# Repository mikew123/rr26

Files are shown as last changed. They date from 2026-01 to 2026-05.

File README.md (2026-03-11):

# DESCRIPTION
This design is for the ROBORAMA 2026 Indoor robot competition<br>
The 2025 robot hardware and code will be used with modifications.<br>
The 2025 ROS based code will be reused, the NAV2 navigation code needs help to allow the robot to move faster.<br>

## DPRG competitions
This robot will compete in the following 4 contests. Barrell racing is a new attempt this year<br>
- 6 Can<br>
https://www.dprg.org/wp-content/uploads/2019/01/sixcan-20190119.pdf<br>
- 4 Corner<br>
https://www.dprg.org/wp-content/uploads/2018/09/four_corners-201804303.pdf<br>
- Quick Trip<br>
https://www.dprg.org/wp-content/uploads/2018/09/quick_trip_v20180130_3.pdf<br>
- Barrell Race<br>
https://www.dprg.org/wp-content/uploads/2025/03/barrel_racing_v20250320.pdf<br>

## Hardware modifications
- The rear IR sensor array and front TOF sensor will be removed
- The LIDAR will be lowered so that it can detect the cans on the field  as well as the walls (the 2025 LIDAR only detected the walls for localization and not the cans), this replaces the front TOF sensor and rear sensors.
- The Raspberry Pi Screen will be removed
- The power module will be improved with better regulators
- The wheel controller module will be moved to make room for a WIFI router in the back
- The caster mount will be filled with lead instead of pennys for for weight and stability
- The can detect switch (or some other sensor) will be mounted on the new can catch 
- A new  3D printed can catch will help keep the cans upright after grabbing - the 2025 design allowed the cans to slide a bit under the chassis

## 2025 Robot Pictures Before Modifications:
Top of robot:<br>
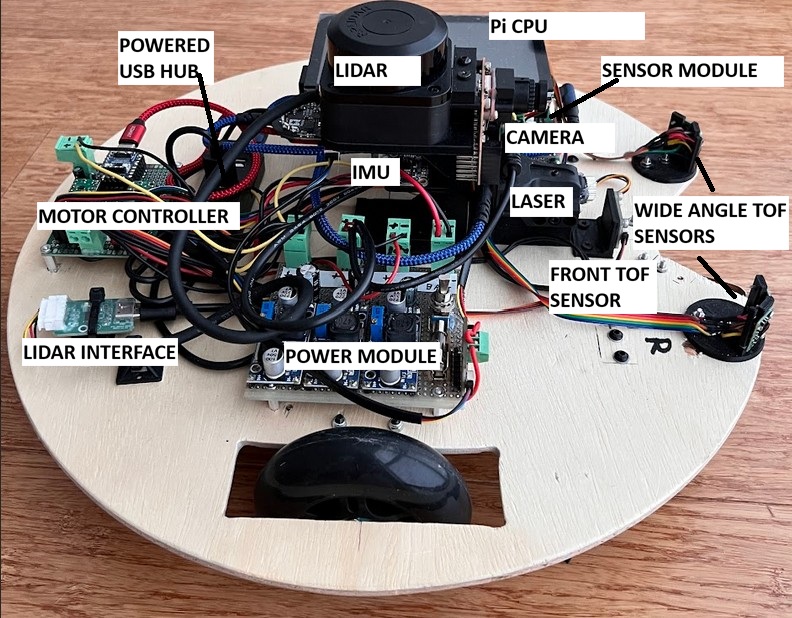
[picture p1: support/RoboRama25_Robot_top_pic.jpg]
Robot top
 <br>
Bottom of robot:<br>
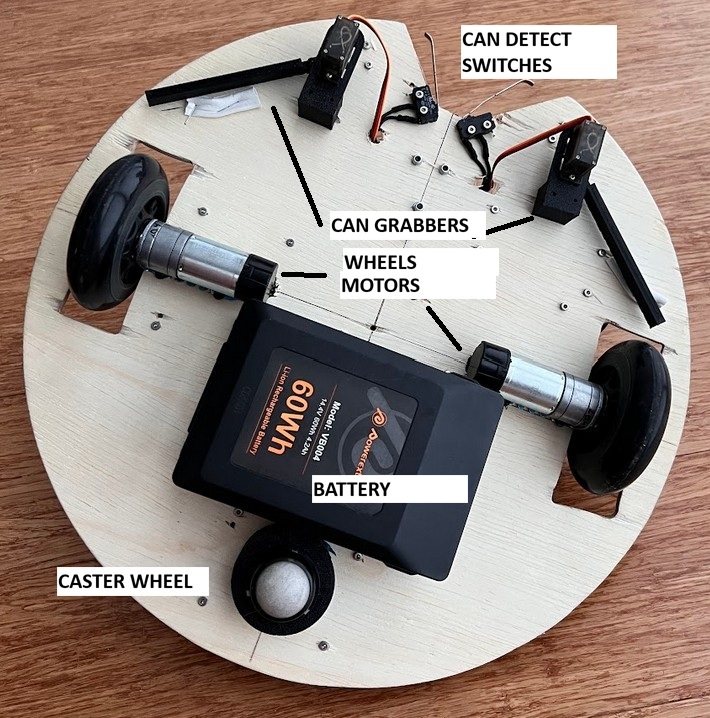
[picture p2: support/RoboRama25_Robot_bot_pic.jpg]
Robot top
 <br>

## Code modifications
- Create a new "scan_obj" topic that blocks the scan rays where the can is detected by the camera. This allows the LIDAR to replace the front TOF sensor when approaching the can.

# Documentation
## Block diagram of electronics:
The Rasberry Pi does not supply power directly to any of the peripherals<br>
The peripheral power is supplied from the power supply module<br>
The powered USB hub supplies power for to the peripherals connected to it<br>
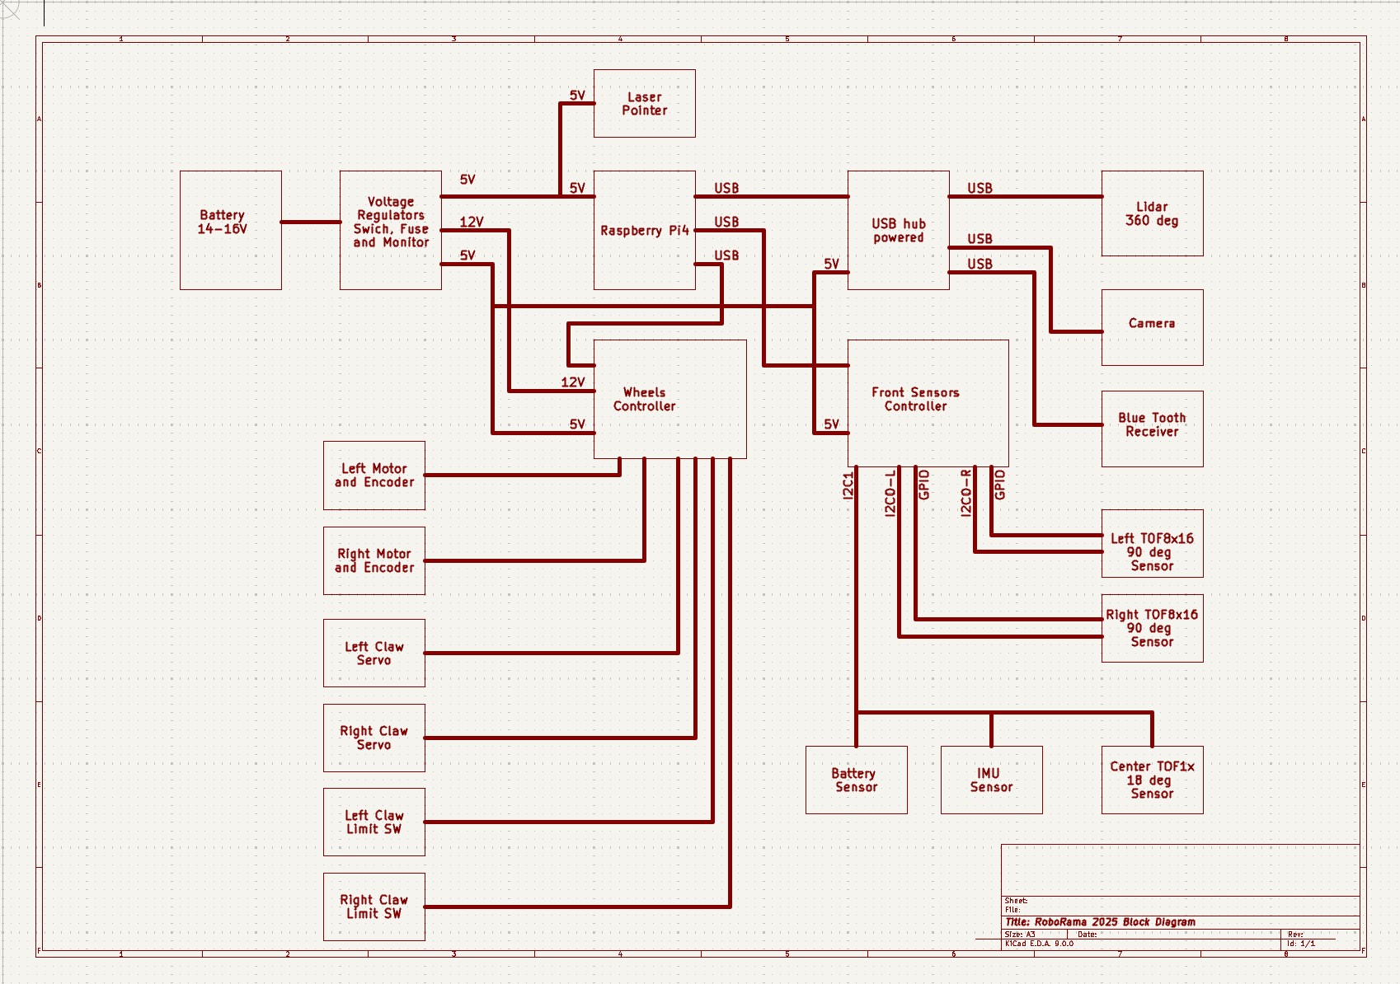
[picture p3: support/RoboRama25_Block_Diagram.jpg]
Block diagram
 <br>

## Schematics:
Power Supply board:<br>
There are 3 voltage regulators. 12V for the wheel motors. A 5V for the Pi and 5V for the peripherals<br>
The Peripheral 5V are bumped up 0.7 volts or so to compensate for the reverse protection diodes<br>
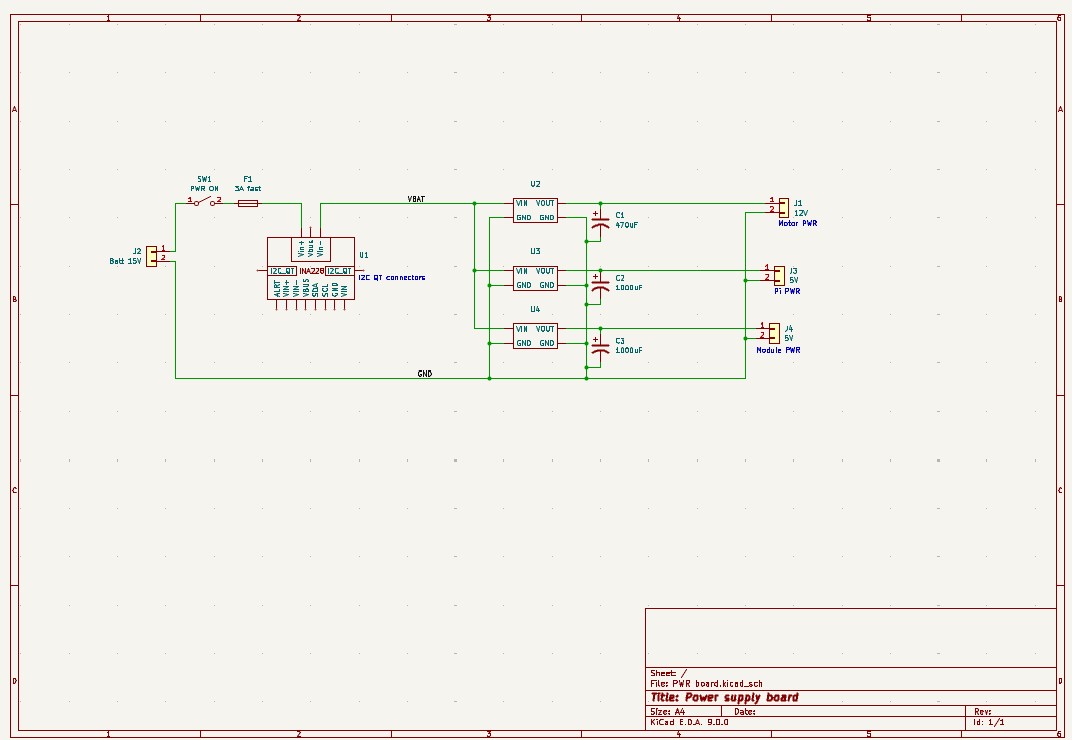
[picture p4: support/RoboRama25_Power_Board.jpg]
Power Supply board
 <br>

Front Sensors Controller board:<br>
The 5V input has a reverse protection diode, the 5V input level is expected to be 5.7V or so to compensate for the diod drop. The 3.3V to the sensors is from a regulator since they need more power than the uC internal regulator can safely generate. The 3.3V regulator can be disabled to reset the VL53L4CX sensors before assigning I2C addresses. The RP2040 module 3.3V output is not used.<br>
The four VL53L4CX sensors are on the I2C0 bus and the I2C1 bus is a QT connector which connects to the other sensors.<br>
The wiring of the VL53L4CX sensors is shown on the schematic, this wiring is not on the Front Sensor Controller board.<br>
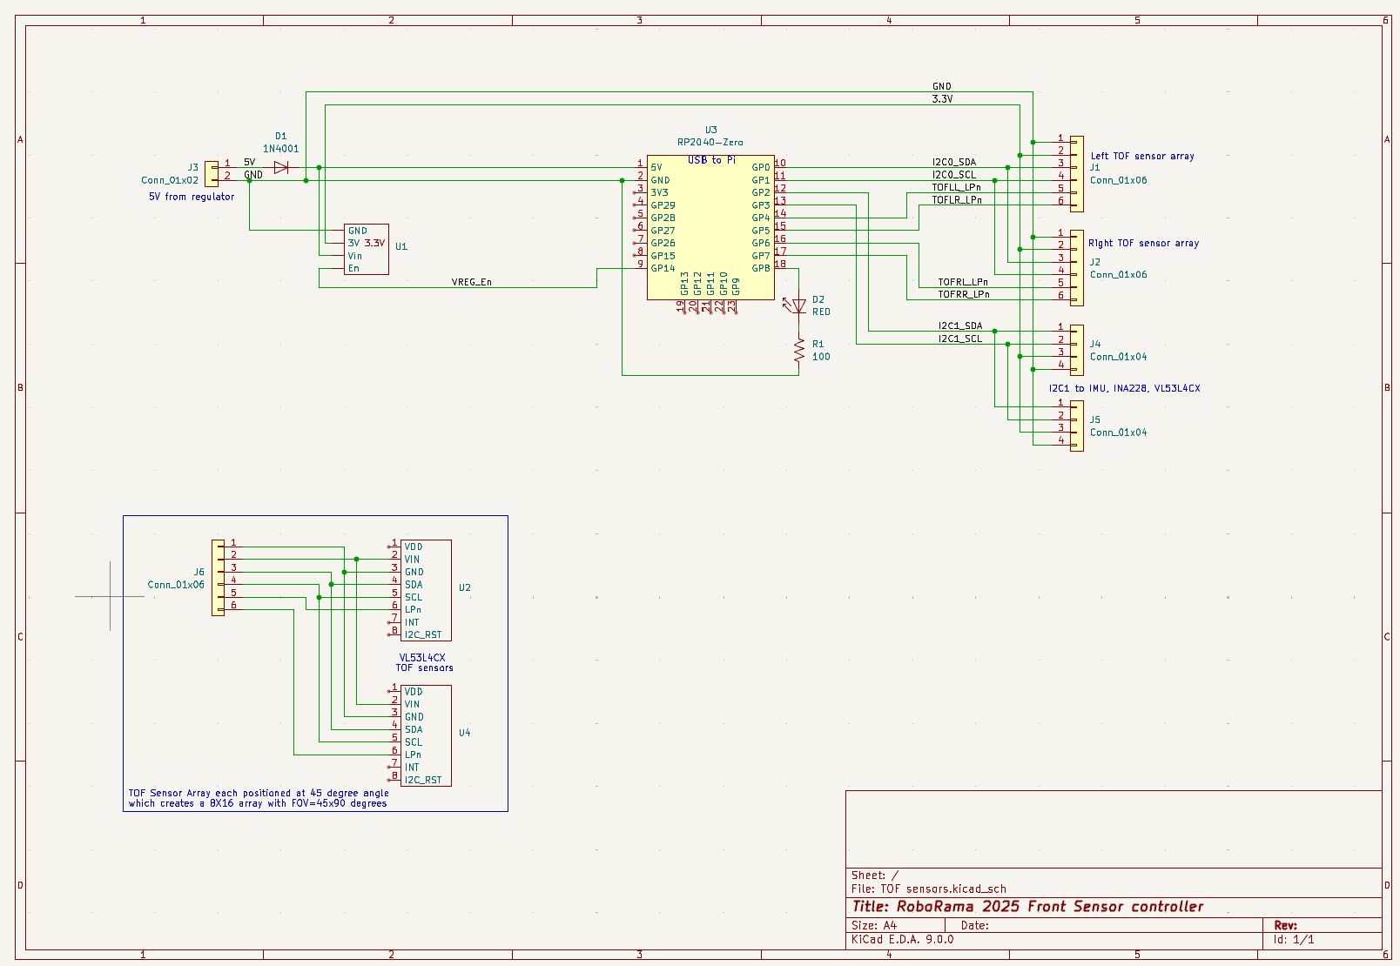
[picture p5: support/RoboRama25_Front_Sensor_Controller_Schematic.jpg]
Front Sensor Controller
 <br>

Wheels Controller board:<br>
The 5V input has a reverse protection diode, the 5V input level is expected to be 5.7V or so to compensate for the diod drop. The RP2040 module 3.3V output powers the pod encoder sensors which do not require a lot of power.<br>
The 12V powers the MP6550 Wheel motor controllers which are connected with a 6 pin cable. The cable also has the motor encoder signals that are powered by 5V and the level shifter connects the signals to the 3.3V GPIO pins of the controller. There is also 4 pin connectors to pod odomtry sensors used on the 2024 robot but not this year.<br>
The 3 pin connectors are for the servos that control the claws operate on 5V and work with the 3.3V GPIO signals. There is a set 2 pin connectors for the limit switches that trip when the can is firmly gripped by the claws, the GPIO pins are configured with internal pull-up resistors so the switches pull the pin levels low when tripped.<br>
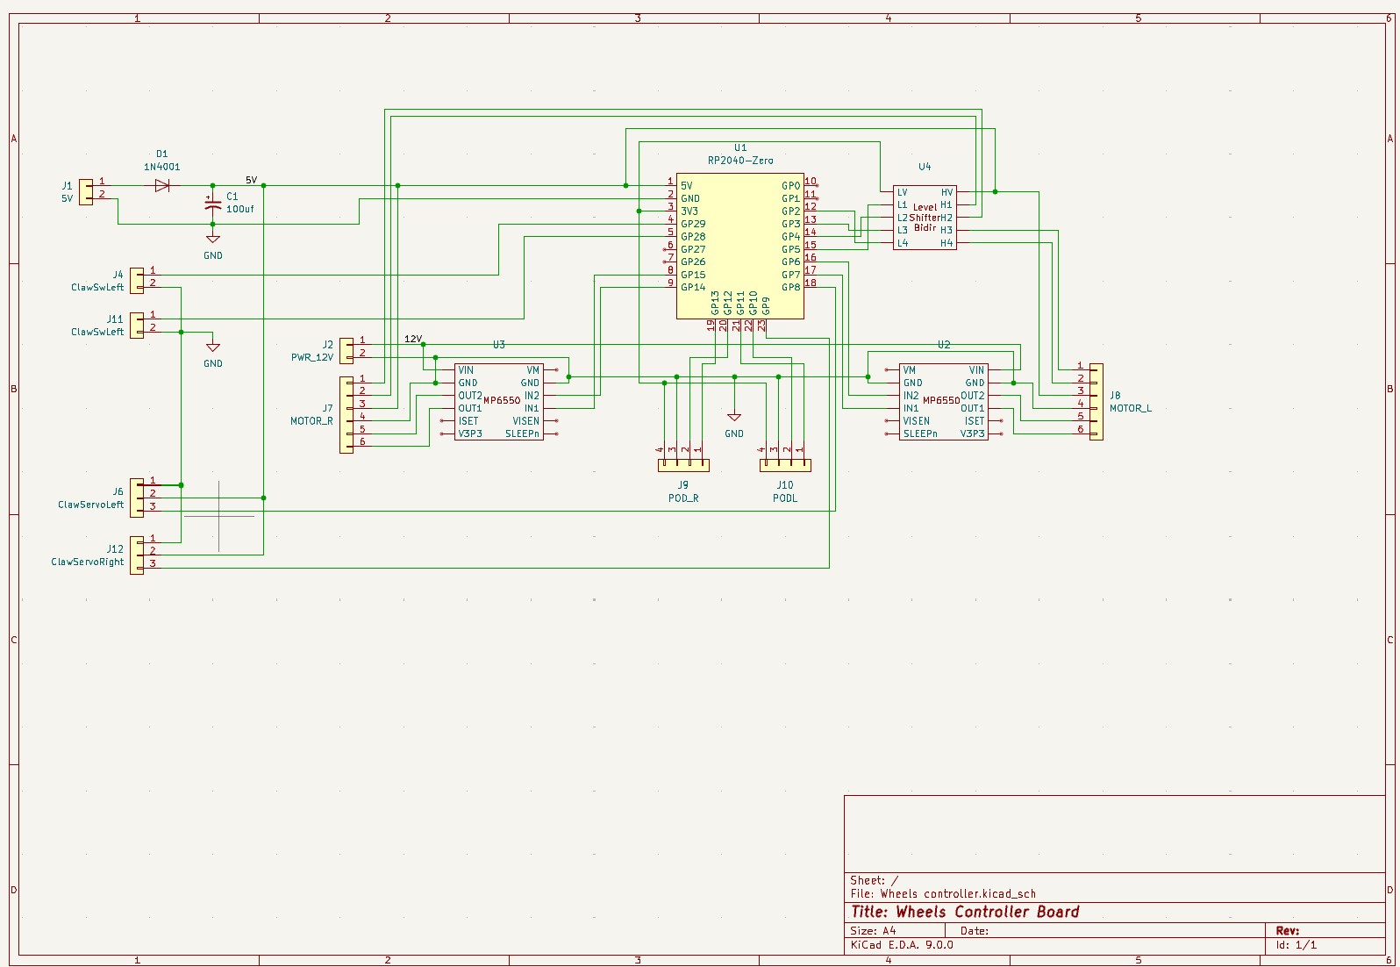
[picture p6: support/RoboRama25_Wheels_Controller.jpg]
Wheels Controller board
 <br>

# ROS2 node package Roborama25 Stuff
(NOTE: These descriptions are created using Co-Pilot)<br>
This package contains nodes and utilities for controlling and managing the Roborama25 robot.<br>

This command line compiles and launches the roborama25 project:<br>
clear; colcon build; source install/setup.bash ; ros2 launch roborama25_stuff roborama25_lc_nav2_bringup_launch.py

## Nodes

### `roborama25_wheel_controller_node_lc`

#### Description
The `roborama25_wheel_controller_node_lc` is a ROS 2 lifecycle node designed to control the robot's differential drive wheels and provide odometry data for the navigation stack. It communicates with a microcontroller (e.g., Raspberry Pi Pico) over a serial interface to send wheel velocity commands and receive encoder data.

#### Features
- **Lifecycle Management**: Implements lifecycle states (`on_configure`, `on_activate`, `on_deactivate`, `on_cleanup`, `on_shutdown`, `on_error`) to manage hardware connections and ROS 2 communications.
- **Wheel Control**: Converts `/cmd_vel` messages into individual wheel velocities and sends them to the microcontroller.
- **Odometry Calculation**: Processes encoder data to calculate the robot's position and orientation, publishing odometry data to the `/wheel_odom` topic.
- **TF Broadcasting**: Broadcasts the transform (`odom -> base_footprint`) using calculated odometry data.
- **Joystick Integration**: Supports joystick-based manual control for resetting encoders and controlling a claw mechanism.
- **Serial Communication**: Handles serial communication with the microcontroller for sending and receiving data.
- **Claw Control**: Processes JSON commands from the `/robot_json` topic to control a claw mechanism.

#### Topics
- **Subscriptions**:
  - `/cmd_vel`: Receives velocity commands for the robot.
  - `/joy`: Processes joystick inputs for additional controls.
  - `/robot_json`: Processes JSON commands for the claw mechanism.
  - `encoders_msg`: Reads encoder data from the serial interface.

- **Publications**:
  - `/wheel_odom`: Publishes odometry data for the navigation stack.
  - `encoders_msg`: Publishes raw encoder data received from the serial interface.
  - `wheel_debug_msg`: Publishes debug messages for wheel-related calculations.

#### Parameters
- **Wheel Configuration**:
  - `wheelDiameter`: Diameter of the wheels.
  - `wheelEncoderCounts`: Encoder counts per wheel rotation.
  - `wheelDistance`: Distance between the two wheels.

- **Velocity Limits**:
  - `wheelVelocityAccLimit`: Maximum acceleration for the wheels.
  - `fwdRevMpsMax`: Maximum forward/reverse speed.

- **Serial Configuration**:
  - `wheel_serial_port_name`: Serial port for communication with the microcontroller.
  - `serialTimerRateHz`: Frequency for checking the serial port.

#### Usage
1. Build the package:
   ```bash
   colcon build --packages-select roborama25_stuff

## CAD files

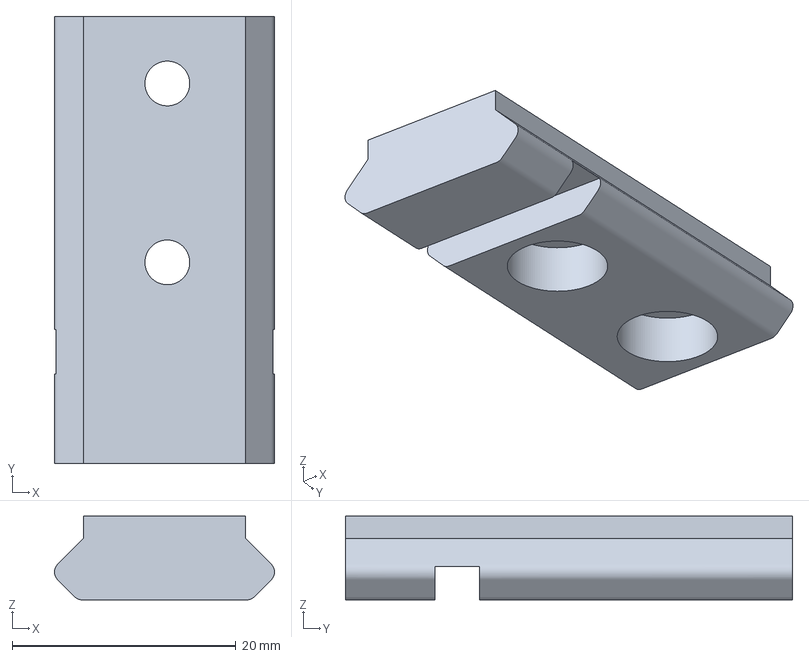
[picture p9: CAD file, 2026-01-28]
3dprinting/Roborama2026-Lasermount.3mf
19.7 x 40.0 x 7.50 mm

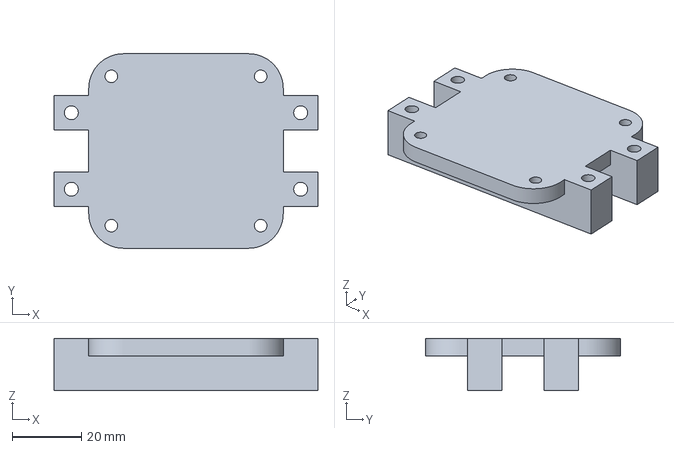
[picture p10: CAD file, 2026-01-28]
3dprinting/Roborama2026-LidarMount.3mf
76.0 x 56.0 x 15.0 mm

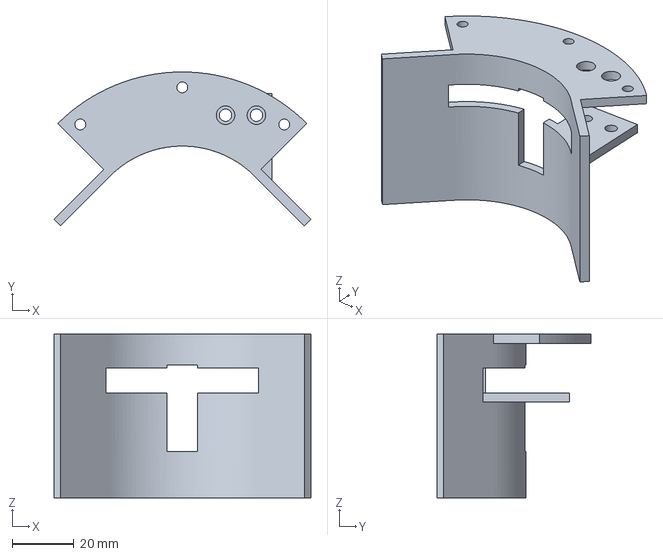
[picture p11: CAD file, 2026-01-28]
3dprinting/Roborama2026-CanBasket.3mf
83.2 x 49.9 x 53.0 mm

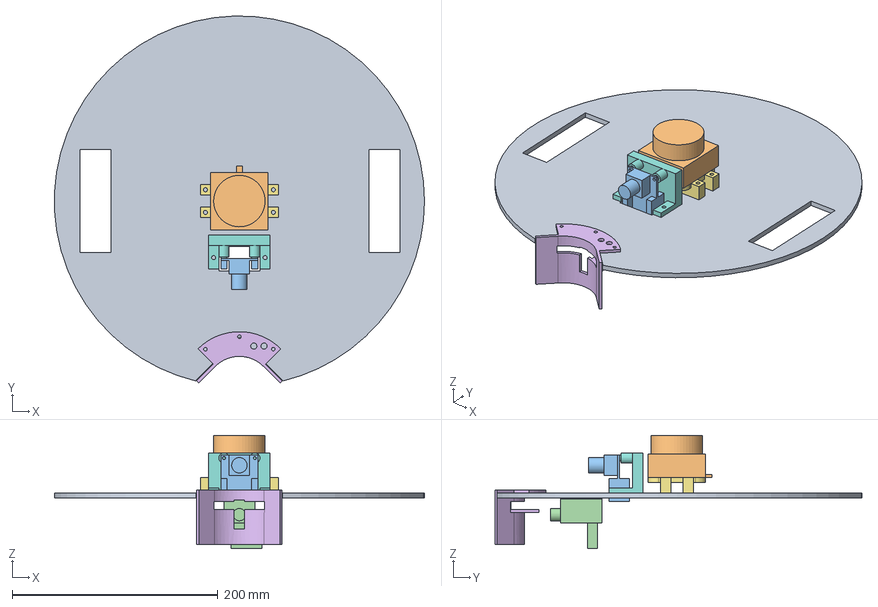
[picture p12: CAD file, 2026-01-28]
3dprinting/Roborama2026.FCStd
359.8 x 356.8 x 110.0 mm
WoodPlatform
LidarC1
Cam
Laser
Lasermount
CanBasket
LidarMount
CamMount

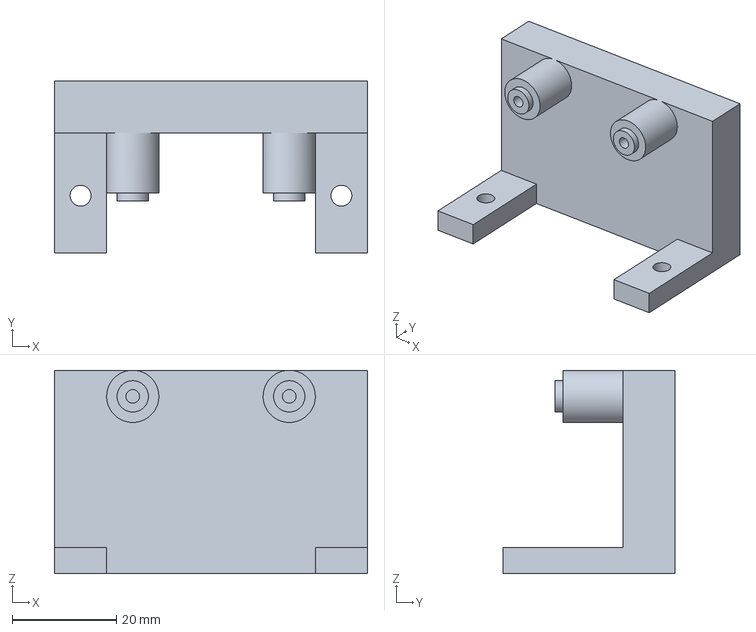
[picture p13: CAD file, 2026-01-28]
3dprinting/Roborama2026-CamMount.3mf
60.0 x 33.0 x 39.0 mm

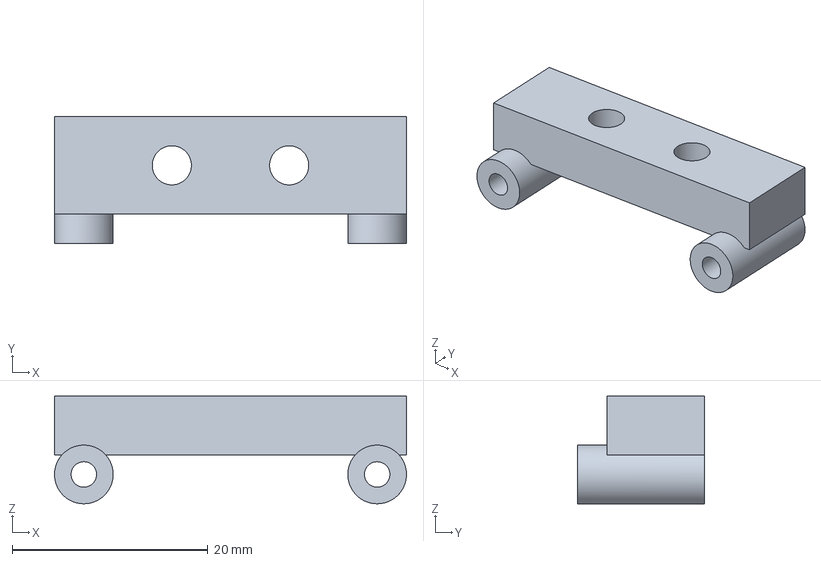
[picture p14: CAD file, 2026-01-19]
3dprinting/Roborama2025-CamMount.amf
36.0 x 13.0 x 11.0 mm

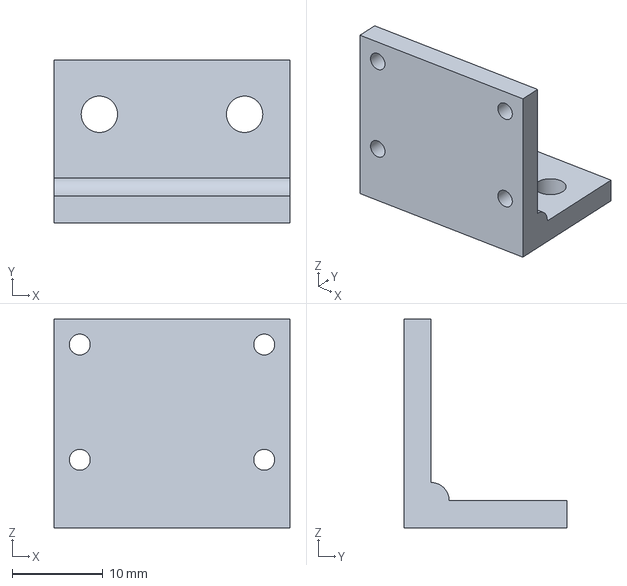
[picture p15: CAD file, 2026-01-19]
3dprinting/Roborama2025-TofL4Mount.amf
26.0 x 18.0 x 23.0 mm

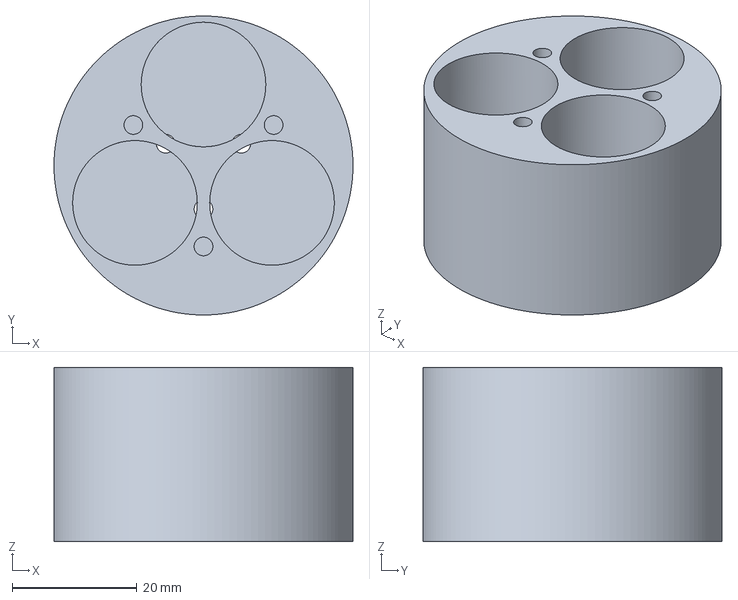
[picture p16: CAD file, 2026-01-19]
3dprinting/Roborama2025-CasterWheelMount.amf
48.0 x 48.0 x 28.0 mm

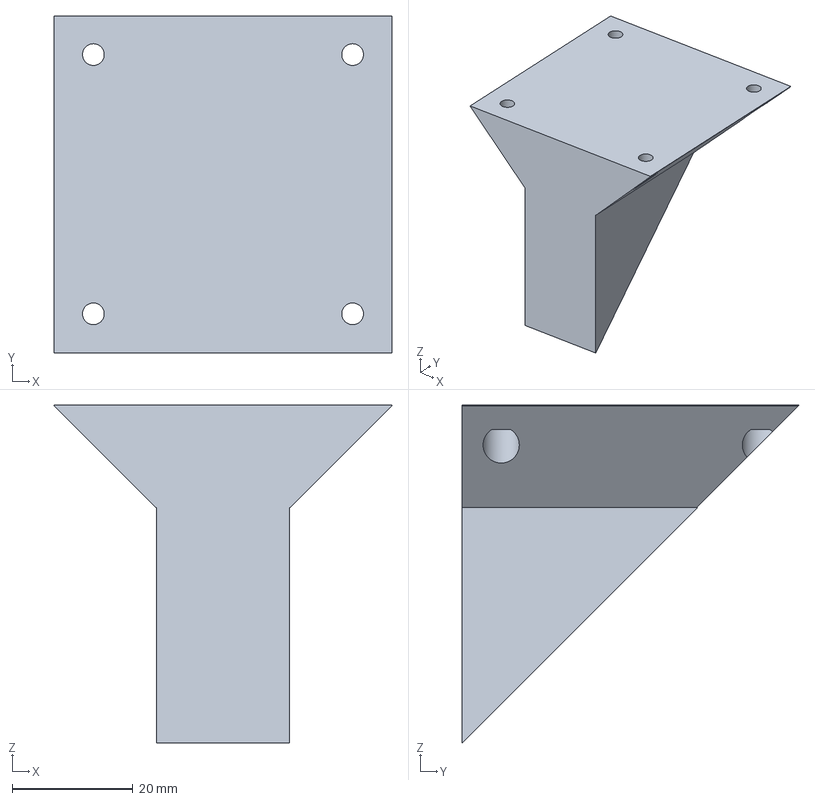
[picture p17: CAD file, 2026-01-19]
3dprinting/Roborama2025-LidarMount.amf
56.0 x 55.9 x 56.0 mm

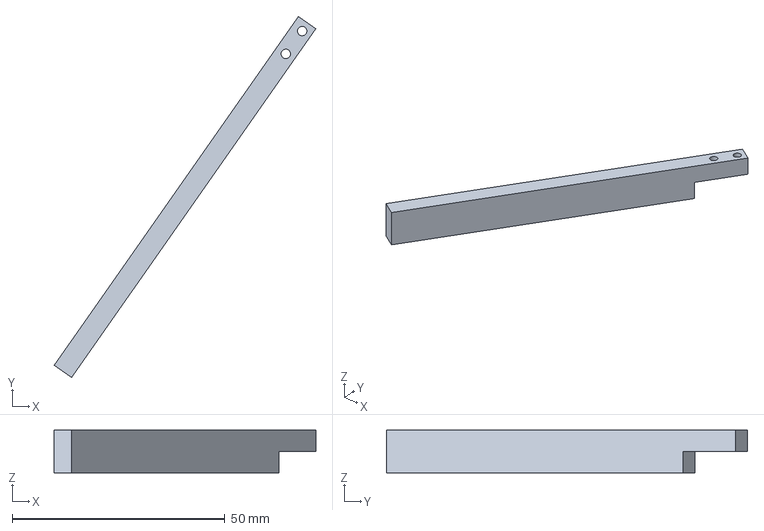
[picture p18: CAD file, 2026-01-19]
3dprinting/Roborama2025-ClawMaster.amf
61.5 x 84.8 x 10.0 mm

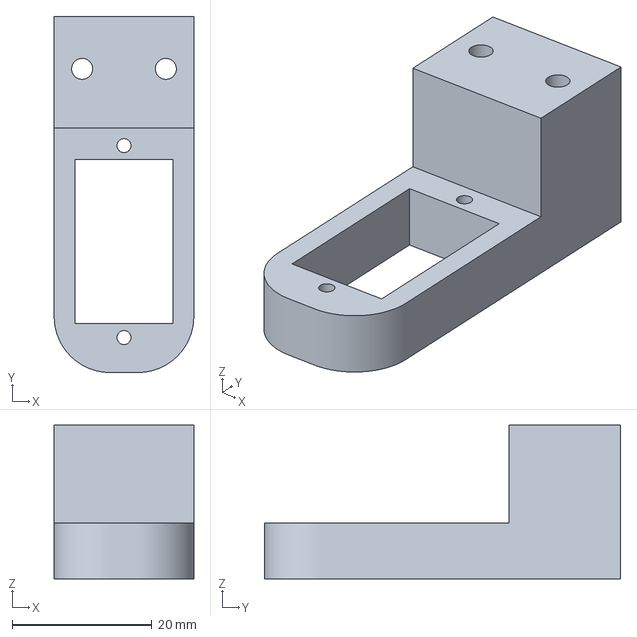
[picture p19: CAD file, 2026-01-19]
3dprinting/Roborama2025-ServoMount.amf
20.0 x 51.0 x 22.0 mm

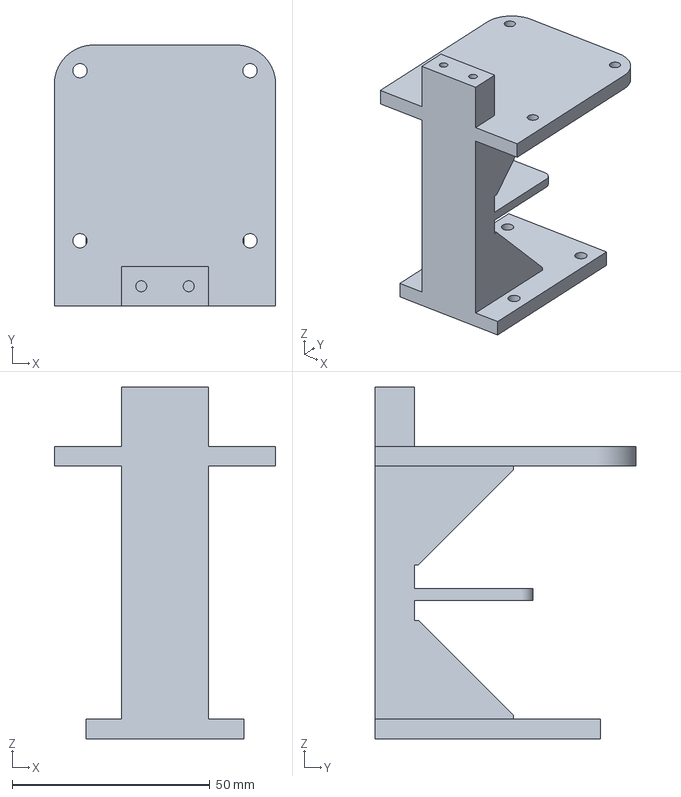
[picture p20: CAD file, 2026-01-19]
3dprinting/Roborama2025-LidarCamImuMount.amf
56.0 x 66.0 x 89.0 mm

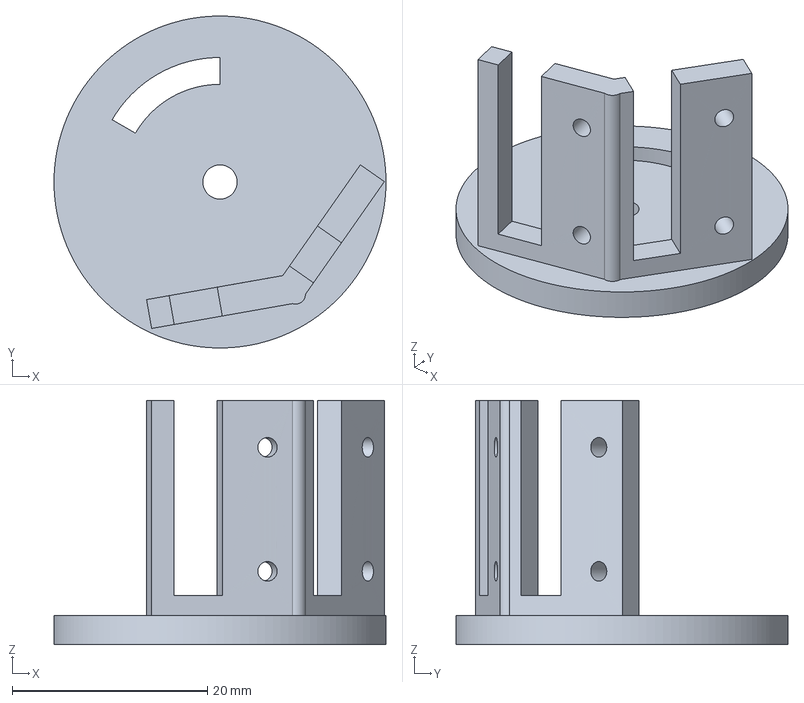
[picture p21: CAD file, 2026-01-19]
3dprinting/Roborama2025-TofL5MountL.amf
34.0 x 34.0 x 25.0 mm

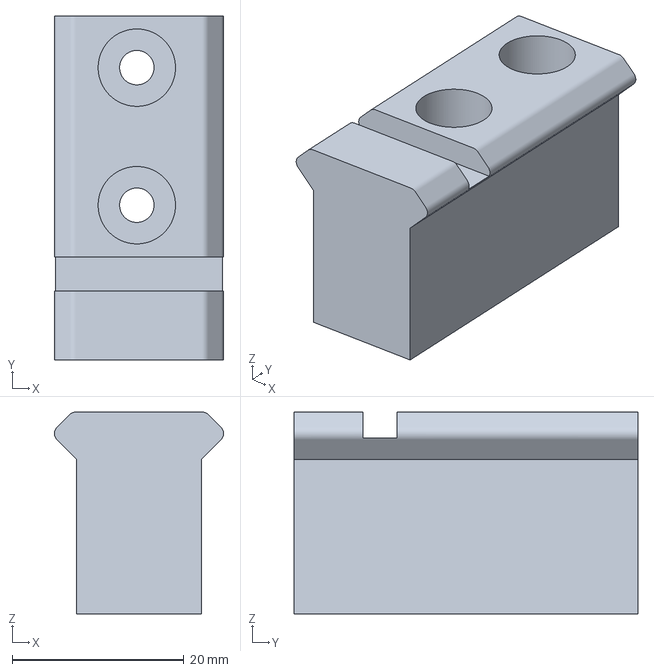
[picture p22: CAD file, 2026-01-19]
3dprinting/Roborama2025-Lasermount.amf
19.7 x 40.0 x 23.5 mm

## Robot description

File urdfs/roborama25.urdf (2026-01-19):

<?xml version="1.0" ?>
<robot name="roborama25" xmlns:xacro="http://ros.org/wiki/xacro">

<!-- Roborama robot model, all joints fixed (even wheels), no camera, link names match udemy_ws turtlebot3 6can -->
  <!-- Init colour -->
  <material name="black">
      <color rgba="0.0 0.0 0.0 1.0"/>
  </material>

  <material name="dark">
    <color rgba="0.3 0.3 0.3 1.0"/>
  </material>

  <material name="light_black">
    <color rgba="0.4 0.4 0.4 1.0"/>
  </material>

  <material name="blue">
    <color rgba="0.0 0.0 0.8 1.0"/>
  </material>

  <material name="green">
    <color rgba="0.0 0.8 0.0 1.0"/>
  </material>

  <material name="grey">
    <color rgba="0.5 0.5 0.5 1.0"/>
  </material>

  <material name="orange">
    <color rgba="1.0 0.4235 0.0392 1.0"/>
  </material>

  <material name="brown">
    <color rgba="0.8706 0.8118 0.7647 1.0"/>
  </material>

  <material name="red">
    <color rgba="0.8 0.0 0.0 1.0"/>
  </material>

  <material name="white">
    <color rgba="1.0 1.0 1.0 1.0"/>
  </material>

  <link name="map"/>

  <!-- map -> odom actively managed by navigation2, this is temporary -->
  <joint name="odom_joint" type="fixed">
    <parent link="map"/>
    <child link="odom" />
    <origin xyz="0 0 0" rpy="0 0 0"/>
  </joint>
  <link name="odom"/>

  <!-- odom -> base_footprint actively managed by wheels node -->
  <joint name="base_footprint_joint" type="fixed">
    <parent link="odom"/>
    <child link="base_footprint" />
    <origin xyz="0 0 0" rpy="0 0 0"/>
  </joint>
  <link name="base_footprint"/>

  <joint name="base_link_joint" type="fixed">
    <parent link="base_footprint"/>
    <child link="base_link" />
    <origin xyz="0 0 0.042" rpy="0 0 0"/>
  </joint>

  <link name="base_link">
    <visual>
      <origin xyz="0 0 0.015" rpy="0 0 0"/>
      <geometry>
        <cylinder length="0.005" radius="0.180"/>
      </geometry>
      <material name="orange"/>
    </visual>
  </link>

  <!-- <joint name="wheel_left_joint" type="continuous"> -->
  <joint name="wheel_left_joint" type="fixed">
    <parent link="base_link"/>
    <child link="wheel_left_link"/>
    <origin xyz="0 0.140 0" rpy="-1.57 0 0"/>
    <!-- <axis xyz="0 0 1"/> -->
  </joint>

  <link name="wheel_left_link">
    <visual>
      <origin xyz="0 0 0" rpy="0 0 0"/>
      <geometry>
        <cylinder length="0.020" radius="0.042"/>
      </geometry>
      <material name="dark"/>
    </visual>
  </link>

  <!-- <joint name="wheel_right_joint" type="continuous"> -->
  <joint name="wheel_right_joint" type="fixed">
    <parent link="base_link"/>
    <child link="wheel_right_link"/>
    <origin xyz="0 -0.140 0" rpy="-1.57 0 0"/>
    <!-- <axis xyz="0 0 1"/> -->
  </joint>

  <link name="wheel_right_link">
    <visual>
      <origin xyz="0 0 0" rpy="0 0 0"/>
      <geometry>
        <cylinder length="0.020" radius="0.042"/>
      </geometry>
      <material name="dark"/>
    </visual>
  </link>

  <joint name="caster_joint" type="fixed">
    <parent link="base_link"/>
    <child link="caster_link"/>
    <origin xyz="-0.125 0 -0.035" rpy="0 0 0"/>
  </joint>

  <link name="caster_link">
    <visual>
      <origin xyz="0 0 0" rpy="0 0 0"/>
      <geometry>
        <sphere radius="0.012"/>
      </geometry>
      <material name="white"/>
    </visual>
    <visual>
      <origin xyz="0 0 0.025" rpy="0 0 0"/>
      <geometry>
        <cylinder length="0.050" radius="0.020"/>
      </geometry>
      <material name="dark"/>
    </visual>
  </link>

  <joint name="imu_joint" type="fixed">
    <parent link="base_link"/>
    <child link="imu_link"/>
    <origin xyz="0 0 0.055" rpy="0 0 0"/>
  </joint>

  <link name="imu_link">
    <visual>
      <origin xyz="0 0 0" rpy="0 0 0"/>
      <geometry>
        <box size="0.015 0.015 0.005"/>
      </geometry>
      <material name="red"/>
    </visual>
  </link>

  <!-- RPLidar C1 direction must be 180 deg to scan correctly -->
  <joint name="lidar_joint" type="fixed">
    <parent link="base_link"/>
    <child link="lidar_link"/>
    <origin xyz="0 0 0.115" rpy="0 0 3.1416"/>
  </joint>

  <link name="lidar_link">
    <visual>
      <origin xyz="0 0 0" rpy="0 0 0"/>
      <geometry>
        <cylinder length="0.020" radius="0.025"/>
      </geometry>
      <material name="red"/>
    </visual>
  </link>

  <!-- 90 deg tof arrays are mounted at an angle -->
  <joint name="tofL5L_joint" type="fixed">
    <parent link="base_link"/>
    <child link="tofL5L_link"/>
    <origin xyz="0.140 0.060 0.030" rpy="0 0 0.41"/>
  </joint>

  <link name="tofL5L_link">
    <visual>
      <origin xyz="0 0 0" rpy="0 0 0"/>
      <geometry>
        <cylinder length="0.030" radius="0.020"/>
      </geometry>
      <material name="red"/>
    </visual>
  </link>

  <joint name="tofL5R_joint" type="fixed">
    <parent link="base_link"/>
    <child link="tofL5R_link"/>
    <origin xyz="0.140 -0.060 0.030" rpy="0 0 -0.41"/>
  </joint>

  <link name="tofL5R_link">
    <visual>
      <origin xyz="0 0 0" rpy="0 0 0"/>
      <geometry>
        <cylinder length="0.030" radius="0.020"/>
      </geometry>
      <material name="red"/>
    </visual>
  </link>

  <joint name="tofL4_joint" type="fixed">
    <parent link="base_link"/>
    <child link="tofL4_link"/>
    <origin xyz="0.100 0 0.030" rpy="0 0 0"/>
  </joint>

  <link name="tofL4_link">
    <visual>
      <origin xyz="0 0 0" rpy="0 0 0"/>
      <geometry>
        <box size="0.005 0.025 0.025"/>
      </geometry>
      <material name="red"/>
    </visual>
  </link>

  <joint name="tofRC_joint" type="fixed">
    <parent link="base_link"/>
    <child link="tofRC_link"/>
    <origin xyz="-0.040 0 0.085" rpy="0 0 3.1416"/>
  </joint>

  <link name="tofRC_link">
    <visual>
      <origin xyz="0 0 0" rpy="0 0 0"/>
        <geometry>
          <cylinder length="0.005" radius="0.015"/>
        </geometry>
      <material name="red"/>
    </visual>
  </link>


  <joint name="tofRL_joint" type="fixed">
    <parent link="base_link"/>
    <child link="tofRL_link"/>
    <origin xyz="-0.040 0 0.085" rpy="0 0 2.3"/>
  </joint>

  <link name="tofRL_link">
    <visual>
      <origin xyz="0 0 0" rpy="0 0 0"/>
        <geometry>
          <cylinder length="0.005" radius="0.015"/>
        </geometry>
      <material name="red"/>
    </visual>
  </link>

  <joint name="tofRR_joint" type="fixed">
    <parent link="base_link"/>
    <child link="tofRR_link"/>
    <origin xyz="-0.040 0 0.085" rpy="0 0 -2.3"/>
  </joint>

  <link name="tofRR_link">
    <visual>
      <origin xyz="0 0 0" rpy="0 0 0"/>
        <geometry>
          <cylinder length="0.005" radius="0.015"/>
        </geometry>
      <material name="red"/>
    </visual>
  </link>

</robot>

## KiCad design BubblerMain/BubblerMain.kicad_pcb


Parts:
C13: 0.1uF; C_1206_3216Metric_Pad1.33x1.80mm_HandSolder
C19: 1000uF; CP_Elec_10x10
J2, J3, J4, J5: Conn_01x03_Pin; JST_XH_B3B-XH-AM_1x03_P2.50mm_Vertical
R9, R10, R11, R12: 330; R_1206_3216Metric_Pad1.30x1.75mm_HandSolder
U1: 74AHCT125; SOIC-14_3.9x8.7mm_P1.27mm; LCSC C2675672

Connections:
+5V: C13.1, C19.1, J2.3, J3.3, J4.3, J5.3, U1.14 (VCC); also elsewhere on the board
GND1: C13.2, C19.2, J2.1, J3.1, J4.1, J5.1, U1.1, U1.4, U1.7 (GND), U1.10, U1.13; also elsewhere on the board
LED1 Signal: U1.2; also elsewhere on the board
LED2 Signal: U1.5; also elsewhere on the board
LED3 Signal: U1.9; also elsewhere on the board
LED4 Signal: U1.12; also elsewhere on the board
unnamed: J2.2, R9.1
unnamed: J3.2, R10.1
unnamed: J4.2, R11.1
unnamed: J5.2, R12.1
unnamed: R9.2, U1.3
unnamed: R10.2, U1.6
unnamed: R11.2, U1.8
unnamed: R12.2, U1.11


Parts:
5V2: TestPoint; TestPoint_Pad_2.0x2.0mm
C1: 220uf; CP_Elec_10x10
C2, C3: 10uf; C_1206_3216Metric_Pad1.33x1.80mm_HandSolder
C4: 0.1uF; C_1210_3225Metric_Pad1.33x2.70mm_HandSolder
C5, C6: 22uF; C_1210_3225Metric_Pad1.33x2.70mm_HandSolder
C7: 0.1uF; C_1206_3216Metric_Pad1.33x1.80mm_HandSolder
D1: SMAJ13A; D_SMA
F1: Polyfuse; Fuse_1812_4532Metric
GND1: TestPoint; TestPoint_Pad_2.0x2.0mm
J1: Conn_01x04_Pin; JST_XH_B2B-XH-AM_1x02_P2.50mm_Vertical
L1: 3.3uH; IND_SPM6530T-3R3M; PARTREV N/A; LCSC C76856
Q1: DMP3013SFV; Diodes_PowerDI3333-8; LCSC C264098
R1, R2: 100k; R_1206_3216Metric_Pad1.30x1.75mm_HandSolder
R5: 54.9k; R_1206_3216Metric_Pad1.30x1.75mm_HandSolder
R6: 10k; R_1206_3216Metric_Pad1.30x1.75mm_HandSolder
U9: TPS565201DDCR; SOT95P280X110-6N; LCSC C327676

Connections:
+5V: 5V2.1, C5.1, C6.1, L1.2, R5.1; also elsewhere on the board
/Power Block/BAT+: F1.2, J1.1
/Power Block/Fuse-Pol: F1.1, Q1.5 (D)
GND1: C1.2, C2.2, C3.2, C5.2, C6.2, C7.2, D1.1 (A1), GND1.1, J1.2, R1.2, R6.2, U9.1 (GND); also elsewhere on the board
Motor Power: C1.1, C2.1, C3.1, C7.1, D1.2 (A2), Q1.1 (S), Q1.2 (S), Q1.3 (S), R2.1, U9.3 (VIN); also elsewhere on the board
unnamed: Q1.4 (G), R1.1
unnamed: R2.2, U9.5 (EN)
unnamed: C4.1, L1.1, U9.2 (SW)
unnamed: C4.2, U9.6 (VBST)
unnamed: R5.2, R6.1, U9.4 (VFB)

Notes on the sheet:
Output Filter
Input Filter
Spike Protection
Reverse Polarity Protection


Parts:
3.3V1, 5V1: LED; LED_1206_3216Metric_Pad1.42x1.75mm_HandSolder
3v3: TestPoint; TestPoint_Pad_2.0x2.0mm
C8, C21: 1uF; C_1206_3216Metric_Pad1.33x1.80mm_HandSolder
C9, C22: 22uF; C_1210_3225Metric_Pad1.33x2.70mm_HandSolder
C20: 0.1uF; C_1206_3216Metric_Pad1.33x1.80mm_HandSolder
D2, D3: SS14; D_SMA
FB1: 600; L_1206_3216Metric
J8: USB_C_Receptacle; USB_C_Receptacle_HCTL_HC-TYPE-C-16P-01A
J9: Conn_01x08_Pin; PinHeader_1x08_P2.54mm_Vertical
J12: Conn_01x08_Pin; PinHeader_1x04_P2.54mm_Vertical
MOTOR1: LED; LED_1206_3216Metric_Pad1.42x1.75mm_HandSolder
R16, R17: 5.1k; R_1206_3216Metric_Pad1.30x1.75mm_HandSolder
R18, R19: 10k; R_1206_3216Metric_Pad1.30x1.75mm_HandSolder
R20, R22: 1.5k; R_1206_3216Metric_Pad1.30x1.75mm_HandSolder
R21, R23, R26: 680; R_1206_3216Metric_Pad1.30x1.75mm_HandSolder
SW1, SW2: SW_Push; SW_SPST_PTS645Sx43SMTR92
SW3: LED; LED_1206_3216Metric_Pad1.42x1.75mm_HandSolder
U4: ESP32-S3-WROOM-1; ESP32-S3-WROOM-2; LCSC C2913198
U5: AP2112K-3.3; SOT-23-5; LCSC C23380830
U6: USBLC6-2SC6; SOT-23-6; LCSC C2827654
USB1: LED; LED_1206_3216Metric_Pad1.42x1.75mm_HandSolder

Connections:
+3V3: 3v3.1, C20.1, C22.1, J12.3, R18.1, R19.1, R21.1, U4.2 (3V3), U5.5 (VOUT); also elsewhere on the board
+5V: FB1.1, J12.4; also elsewhere on the board
/ESP32/A6: J8.A6 (D+), J8.B6 (D+), U6.4 (I/O2)
/ESP32/A7: J8.A7 (D-), J8.B7 (D-), U6.6 (I/O1)
/ESP32/GPIO8: J9.1, U4.12 (IO8)
/ESP32/GPIO9: J9.2, U4.17 (IO9)
/ESP32/GPIO10: J9.3, U4.18 (IO10)
/ESP32/GPIO11: J9.4, U4.19 (IO11)
/ESP32/GPIO12: J9.5, U4.20 (IO12)
/ESP32/GPIO13: J9.6, U4.21 (IO13)
/ESP32/GPIO14: J9.7, U4.22 (IO14)
/ESP32/GPIO21: J9.8, U4.23 (IO21)
/ESP32/SW_LED: R23.1, U4.25 (IO48)
/ESP32/VBUS: D2.2 (A), J8.A4 (VBUS), J8.A9 (VBUS), J8.B4 (VBUS), J8.B9 (VBUS), R22.1, U6.5 (VBUS)
GND1: 3.3V1.1 (K), 5V1.1 (K), C8.2, C9.2, C20.2, C21.2, C22.2, J8.A1 (GND), J8.A12 (GND), J8.B1 (GND), J8.B12 (GND), J12.1, MOTOR1.1 (K), R16.2, R17.2, SW1.1, SW2.2, SW3.1 (K), U4.1 (GND), U4.40 (GND), U4.41 (GND), U5.2 (GND), U6.2 (GND), USB1.1 (K); also elsewhere on the board
I2S_SCK: U4.9 (IO16); also elsewhere on the board
I2S_SD: U4.11 (IO18); also elsewhere on the board
I2S_WS: U4.10 (IO17); also elsewhere on the board
LED1 Signal: U4.4 (IO4); also elsewhere on the board
LED2 Signal: U4.5 (IO5); also elsewhere on the board
LED3 Signal: U4.6 (IO6); also elsewhere on the board
LED4 Signal: U4.7 (IO7); also elsewhere on the board
Motor Power: J12.2; also elsewhere on the board
Motor Signal: R26.1, U4.8 (IO15); also elsewhere on the board
unnamed 26: 3.3V1.2 (A), R21.2; also elsewhere on the board
unnamed 27: 5V1.2 (A), R20.2; also elsewhere on the board
unnamed: C8.1, C9.1, D2.1 (K), D3.1 (K), R20.1, U5.1 (VIN), U5.3 (EN)
unnamed: D3.2 (A), FB1.2
unnamed: MOTOR1.2 (A), R26.2
unnamed 45: R23.2, SW3.2 (A); also elsewhere on the board
unnamed: C21.1, R18.2, SW1.2, U4.3 (EN)
unnamed: R19.2, SW2.1, U4.27 (IO0)
unnamed: U4.14 (USB_D+/IO20), U6.3 (I/O2)
unnamed: U4.13 (USB_D-/IO19), U6.1 (I/O1)
unnamed 57: R22.2, USB1.2 (A); also elsewhere on the board
RS485_DE: U4.35 (MTMS/IO42); also elsewhere on the board
RS485_RX: U4.38 (IO2); also elsewhere on the board
RS485_TX: U4.39 (IO1); also elsewhere on the board

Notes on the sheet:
Expansion Header for future use


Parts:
C8, C21: 1uF
C20: 0.1uF
C22: 22uF
D2: SS14
D4, D5, D6, D7: LED
J8: USB_C_Receptacle
R16, R17: 5.1k
R18, R19: 10k
R20, R22: 1.5k
R21, R23: 680
SW1, SW2: SW_Push
U4: ESP32-S3-WROOM-1; ESP32-S3-WROOM-2
U5: AP2112K-3.3; SOT-23-5
U6: USBLC6-2SC6; SOT-23-6

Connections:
+3V3: C20.1, C22.1, R18.1, R19.1, R21.1, U4.2 (3V3), U5.5 (VOUT); also elsewhere on the board
/ESP32/A6: J8.A6 (D+), J8.B6 (D+), U6.4 (I/O2)
/ESP32/A7: J8.A7 (D-), J8.B7 (D-), U6.6 (I/O1)
/ESP32/GPIO8: U4.12 (IO8); also elsewhere on the board
/ESP32/GPIO9: U4.17 (IO9); also elsewhere on the board
/ESP32/GPIO10: U4.18 (IO10); also elsewhere on the board
/ESP32/GPIO11: U4.19 (IO11); also elsewhere on the board
/ESP32/GPIO12: U4.20 (IO12); also elsewhere on the board
/ESP32/GPIO13: U4.21 (IO13); also elsewhere on the board
/ESP32/GPIO14: U4.22 (IO14); also elsewhere on the board
/ESP32/GPIO21: U4.23 (IO21); also elsewhere on the board
/ESP32/SW_LED: R23.1, U4.25 (IO48)
/ESP32/VBUS: D2.2 (A), J8.A4 (VBUS), J8.A9 (VBUS), J8.B4 (VBUS), J8.B9 (VBUS), R22.1, U6.5 (VBUS)
GND1: C8.2, C20.2, C21.2, C22.2, D4.1 (K), D5.1 (K), D6.1 (K), D7.1 (K), J8.A1 (GND), J8.A12 (GND), J8.B1 (GND), J8.B12 (GND), R16.2, R17.2, SW1.1, SW2.2, U4.1 (GND), U4.40 (GND), U4.41 (GND), U5.2 (GND), U6.2 (GND); also elsewhere on the board
I2S_SCK: U4.9 (IO16); also elsewhere on the board
I2S_SD: U4.11 (IO18); also elsewhere on the board
I2S_WS: U4.10 (IO17); also elsewhere on the board
LED1 Signal: U4.4 (IO4); also elsewhere on the board
LED2 Signal: U4.5 (IO5); also elsewhere on the board
LED3 Signal: U4.6 (IO6); also elsewhere on the board
LED4 Signal: U4.7 (IO7); also elsewhere on the board
Motor Signal: U4.8 (IO15); also elsewhere on the board
unnamed 26: D5.2 (A), R21.2; also elsewhere on the board
unnamed 27: D4.2 (A), R20.2; also elsewhere on the board
unnamed 28: C8.1, D2.1 (K), R20.1, U5.1 (VIN), U5.3 (EN); also elsewhere on the board
unnamed 45: D7.2 (A), R23.2; also elsewhere on the board
unnamed: C21.1, R18.2, SW1.2, U4.3 (EN)
unnamed: R19.2, SW2.1, U4.27 (IO0)
unnamed: U4.14 (USB_D+/IO20), U6.3 (I/O2)
unnamed: U4.13 (USB_D-/IO19), U6.1 (I/O1)
unnamed 57: D6.2 (A), R22.2; also elsewhere on the board
RS485_DE: U4.35 (MTMS/IO42); also elsewhere on the board
RS485_RX: U4.38 (IO2); also elsewhere on the board
RS485_TX: U4.39 (IO1); also elsewhere on the board


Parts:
C14, C15: 10uF 25v; C_1206_3216Metric_Pad1.33x1.80mm_HandSolder
C16: 0.1uF; C_1206_3216Metric_Pad1.33x1.80mm_HandSolder
C17, C18: 22uF; C_1210_3225Metric_Pad1.33x2.70mm_HandSolder
J6, J7: Conn_01x02_Pin; JST_XH_B2B-XH-AM_1x02_P2.50mm_Vertical
L2: 3.3uH; IND_SPM6530T-3R3M; PARTREV N/A; LCSC C76856
R13: 35.7k; R_1206_3216Metric_Pad1.30x1.75mm_HandSolder
R14: 10k; R_1206_3216Metric_Pad1.30x1.75mm_HandSolder
R15: 100k; R_1206_3216Metric_Pad1.30x1.75mm_HandSolder
U3: TPS563201DDCR; TSOT-23-6_HandSoldering; PARTREV December 2015; LCSC C116592

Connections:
GND1: C14.2, C15.2, C17.2, C18.2, J6.1, J7.1, R14.2, R15.2, U3.1 (GND); also elsewhere on the board
Motor Power: C14.1, C15.1, U3.3 (VIN); also elsewhere on the board
Motor Signal: R15.1, U3.5 (EN); also elsewhere on the board
unnamed: C17.1, C18.1, J6.2, J7.2, L2.2, R13.1
unnamed: C16.1, L2.1, U3.2 (SW)
unnamed: C16.2, U3.6 (VBST)
unnamed: R13.2, R14.1, U3.4 (VFB)


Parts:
C23, C24: 0.1uF; C_1206_3216Metric_Pad1.33x1.80mm_HandSolder
C25: 4.7uF; C_1206_3216Metric_Pad1.33x1.80mm_HandSolder
J10: Conn_01x04_Pin; JST_XH_B2B-XH-AM_1x02_P2.50mm_Vertical
J11: Conn_01x08_Pin; JST_XH_B8B-XH-AM_1x08_P2.50mm_Vertical
R24, R29: 100k; R_1206_3216Metric_Pad1.30x1.75mm_HandSolder
R25: 120; R_1206_3216Metric_Pad1.30x1.75mm_HandSolder
R27, R28: 33; R_1206_3216Metric_Pad1.30x1.75mm_HandSolder
U7: THVD1400D; SOIC-8_3.9x4.9mm_P1.27mm; LCSC C3235232
U8: SM712; SOT23-WIDE; LCSC C502564

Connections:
+3V3: C23.1, C24.1, C25.1, J11.1, U7.8 (VCC); also elsewhere on the board
GND1: C23.2, C24.2, C25.2, J11.2, J11.4, J11.6, J11.8, R24.2, R29.2, U7.5 (GND), U8.3; also elsewhere on the board
I2S_SCK: R27.2; also elsewhere on the board
I2S_SD: J11.7, R29.1; also elsewhere on the board
I2S_WS: R28.2; also elsewhere on the board
unnamed: J10.1, R25.2, U7.7 (B), U8.1
unnamed: J10.2, R25.1, U7.6 (A), U8.2
unnamed: J11.3, R27.1
unnamed: J11.5, R28.1
RS485_DE: R24.1, U7.2 (~RE), U7.3 (DE); also elsewhere on the board
RS485_RX: U7.1 (RO); also elsewhere on the board
RS485_TX: U7.4 (DI); also elsewhere on the board

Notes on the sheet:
RS485 Transceiver
INMP441 Module Header
INMP441 Module will be on an 8-10 inch lead from the PCB Connected with CAT5 twisted pair. Ground/Signal for each twisted pair.

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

Board: 4 copper layers, 72.0 x 66.0 mm, 85 parts (0 on the bottom side), 63 nets.

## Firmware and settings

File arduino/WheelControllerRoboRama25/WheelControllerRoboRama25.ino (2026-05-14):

#define _PWM_LOGLEVEL_        0
#include "RP2040_PWM.h"
#include "pio_encoder.h"
#include <Servo.h>

// Can be included as many times as necessary, without `Multiple Definitions` Linker Error
#include "RPi_Pico_TimerInterrupt.h"

// Instance RPI_PICO_Timer
RPI_PICO_Timer ITimer1(1);

// Instance Claw servos for Left and Right
Servo myservoL;
Servo myservoR;

//#define PI 3.14159265

// Motor PWM frequency
float frequency = 5000;

// WHEEL 
//#define WHEEL_RADUIS_M (0.080/2)
#define WHEEL_RADUIS_M (0.084/2)
#define WHEEL_CIRCUMFERENCE_M (2*PI*WHEEL_RADUIS_M)
#define WHEEL_ENCODER_COUNT_PER_ROTATION (48*20.4086666)
//#define WHEEL_DIST0_RADIUS_M (0.160)
#define WHEEL_DIST0_RADIUS_M (0.275)

// ODOM POD
#define ODOM_RADUIS_M (0.048/2)
#define ODOM_CIRCUMFERENCE_M (2*PI*ODOM_RADUIS_M)
#define ODOM_ENCODER_COUNT_PER_ROTATION (2000.0)


// global variables that can be updated over serial interface
int EncoderSendRateHz = 1; // msg= OR Hz
float wheelFwdOffsetCal = 1.000; // msg= WO fwd rev
float wheelRevOffsetCal = 1.000;
float wheelAccellerationMaxMpsPs = 1.0;
//float wheelAccellerationMinMps = 0.01;
float wheelCircumferenceM = WHEEL_CIRCUMFERENCE_M;

// not yet updatable

const float PidPropCoef[2] = {-2.0, -2.0};
const float PidIntCoef[2] = {-0.1, -0.1};

//#define PIN0 0 /* I2C */
//#define PIN1 1 /* I2C */
//#define PIN8 26
//#define PIN8 27

// Wheel motor odometry pins
#define PIN_MOTOR_ODOM_RA 4
#define PIN_MOTOR_ODOM_RB 5
#define PIN_MOTOR_ODOM_LA 2
#define PIN_MOTOR_ODOM_LB 3

// Wheel motor driver pins
#define PIN_MOTOR_L1      6
#define PIN_MOTOR_L2      7
#define PIN_MOTOR_R1      14
#define PIN_MOTOR_R2      15


// Odometry Pod odometry pins
#define PIN_POD_ODOM_X1 10
#define PIN_POD_ODOM_X2 11
#define PIN_POD_ODOM_Y1 12
#define PIN_POD_ODOM_Y2 13

#define PIN_SERVO_L  8
#define PIN_SERVO_R  9
#define PIN_LIMSW_L 28
#define PIN_LIMSW_R 29

//creates pwm instance for motor drive
RP2040_PWM* PWM_MOTOR_L1;
RP2040_PWM* PWM_MOTOR_L2;
RP2040_PWM* PWM_MOTOR_R1;
RP2040_PWM* PWM_MOTOR_R2;

// Odometry encoder encoders (Input even pin of encoder pin pairs)
PioEncoder encoder[4] = {PIN_MOTOR_ODOM_RA, PIN_MOTOR_ODOM_LA, PIN_POD_ODOM_X1, PIN_POD_ODOM_Y1};
enum {
  encoderR_e = 0, // right wheel
  encoderL_e = 1, // left wheel
  encoderX_e = 2, // X direction Odom Pod
  encoderY_e = 3  // Y direction Odom Pod (angle)// Alternate way servo.writeMicroseconds(us) may aloow > 0-180
};

int encoderPolarity[4] = {-1,1,-1,1};
int32_t currEncoderCount[4] = {0,0,0,0};

int32_t lastEncoderCount[2] = {0,0};
int16_t diffEncoderCount[2] = {0,0};
double currTravelMeters[2] = {0,0};
double diffTravelMeters[2] = {0,0};
double velocityMPS[2] = {0,0};
uint32_t currTimeUs = 0;
uint32_t lastTimeUs = 0;
uint32_t diffTimeUs = 0;

// Min and Max 180 movement for the 2 servos used
#define clawUsecMinL  775 /*700 /*600 /* CLOSED */
#define clawUsecMaxL 2550 /*2300 /*2150 /* OPENED */

#define clawUsecMinR  400 /*650 /*750 /* OPENED */
#define clawUsecMaxR 2250 /*2375 /*2300 /* CLOSED */

void InitServos() {
  myservoL.attach(PIN_SERVO_L, clawUsecMinL, clawUsecMaxL);
  myservoR.attach(PIN_SERVO_R, clawUsecMinR, clawUsecMaxR);
  OperateClaws(0,0);
  // Init limit switches
  pinMode(PIN_LIMSW_L, INPUT_PULLUP);
  pinMode(PIN_LIMSW_R, INPUT_PULLUP);

}

// Repeat calls in loop until true is returned
// Claws can be operated 0 to 100 percent at a set time interval
// Returns currently operating true/false

// persistant variables
uint32_t clawStopTime = 0; // time clow positiong stops
uint32_t clawNextTime = 0; // next time to make a claw movement
float clawCurrentPct = 0; // claws current percent position
float clawChangePct = 0;

bool OperateClaws(int clawDesiredPct, int clawPeriodMs) {
  bool operating = true;
  float dt = 10.0; // 10 ms constant update period msec
  uint32_t now = millis();

  // Read limit switches
  bool limSwL = !digitalRead(PIN_LIMSW_L);
  bool limSwR = !digitalRead(PIN_LIMSW_R);
// Serial.print(" SW="); Serial.println(limSwR);

  // Is the claw opening or closing?
  bool closing = clawCurrentPct < clawDesiredPct;


  // limit operating time 0 to 10 sec
  if (clawPeriodMs<0) clawPeriodMs = 0;
  if (clawPeriodMs>10000) clawPeriodMs = 10000;

  // initialize new claw positioning, exe once for each claw positioning
  if (clawNextTime==0) {
    clawStopTime = now + clawPeriodMs;
    clawNextTime = now;
    clawChangePct = clawDesiredPct - clawCurrentPct;
  } 
  
  // Operate claw until time finished or closing with can secured 
  if (now >= clawNextTime) {

    // Limit claw range 0 to 100 percent
    if (clawDesiredPct<0) clawDesiredPct=0;
    if (clawDesiredPct>100) clawDesiredPct=100;

    if (clawDesiredPct != int(clawCurrentPct)) {
      // determine claw position for this time interval
      if(clawPeriodMs==0) { 
        // instant claw positioning
        clawCurrentPct = float(clawDesiredPct);
      } else {
          clawCurrentPct += clawChangePct / (float(clawPeriodMs)/dt);
      }
    }

    int clawUsecRangeL = clawUsecMaxL - clawUsecMinL;
    int clawUsecL = clawUsecMaxL - clawUsecRangeL*clawCurrentPct/100;
    int clawUsecRangeR = clawUsecMaxR - clawUsecMinR;
    int clawUsecR = clawUsecMinR + clawUsecRangeR*clawCurrentPct/100;

    // Stop closing claws when Right limit switch is triggered
    if(!(closing && limSwR)) {
      myservoL.writeMicroseconds(clawUsecL);
      myservoR.writeMicroseconds(clawUsecR);
      Serial.print("Operating Claws closing= "); Serial.print(closing);
      Serial.print (" SW= "); Serial.print(limSwR);
      Serial.print(" Lus= "); Serial.print(clawUsecL);
      Serial.print(" Rus= "); Serial.print(clawUsecR);
      Serial.println();
    }


    // if(operating && limSwR) {
    //   // Back off to reduce servo chatter
    //   clawCurrentPct-=4;
    //   clawUsecL = clawUsecMaxL - clawUsecRangeL*clawCurrentPct/100;
    //   clawUsecR = clawUsecMinR + clawUsecRangeR*clawCurrentPct/100;
    //   Serial.println("Claw backing off 4%");
    //   myservoL.writeMicroseconds(clawUsecL);
    //   myservoR.writeMicroseconds(clawUsecR);
    //   clawStopTime = 0;
    //   clawNextTime = 0;
    //   operating = false;
    // } 
    // else if (clawPeriodMs>0) {
    if (clawPeriodMs>0) {
      clawNextTime =  now + dt;
      operating = true;
    } 
    else {
      clawStopTime = 0;
      clawNextTime = 0;
      operating = false;
    }
Serial.print("P="); Serial.print(clawCurrentPct);
Serial.print(" C="); Serial.print(closing);
Serial.print(" D="); Serial.print(dt);
Serial.print(" L="); Serial.print(limSwL);
Serial.print(" R="); Serial.println(limSwR);
  } 
  else if (now >= clawStopTime) {
    clawStopTime = 0;
    clawNextTime = 0;
    operating = false;
  }

// DEBUG

  // Serial.print(operating); Serial.print(" ");
  // Serial.print(now);Serial.print(" ");
  // Serial.print(clawNextTime);Serial.print(" ");
  // Serial.print(clawStopTime);Serial.print(" ");
  // Serial.print(clawPeriodMs);Serial.print(" ");
  // Serial.print(clawChangePct);Serial.print(" ");
  // Serial.println(clawCurrentPct);

  return operating;
}

void ResetEncoderValues() {
  currTimeUs = micros();
  lastTimeUs = currTimeUs;
  diffTimeUs = 0;

  for(int enc=0; enc<4; enc++) {
    currEncoderCount[enc] = 0;
  }

  // only R and L wheel encoders
  for(int enc=0; enc<2; enc++) {
    lastEncoderCount[enc] = 0;
    diffEncoderCount[enc] = 0;
    currTravelMeters[enc] = 0;
    diffTravelMeters[enc] = 0;
    velocityMPS[enc] = 0;
  }
}

// wheel velocity in Meters Per Second
// WheelMps{Right, Left} = {0,0}
volatile float WheelMps[2] = {0.0, 0.0};
volatile float WheelMpsAccLimited[2] = {0.0, 0.0};
// Wheel motor drive percents initial
volatile float MotorPct[2] = {0.0,0.0};
const float WheelMpsMax = 1.0; // +- max

// PID parameter and integral
volatile float PidErrorMps[2] = {0.0, 0.0};
volatile float PidPropPct[2] = {0.0, 0.0};
volatile float PidIntPct[2] = {0.0, 0.0};
const float PidIntPctMax = 100.0; // +- max


// Read encoders using an ISR timer of 10us
bool timerInterruptHandler(struct repeating_timer *t) {
//void updateEncoderCountsISR() {
  (void) t;   

  // read wheel and pod encoders
  currTimeUs = micros();
  for(int enc=0; enc<4; enc++) {
    currEncoderCount[enc] = encoder[enc].getCount() * encoderPolarity[enc];
  }

  // Time from last encoder read
  diffTimeUs = currTimeUs - lastTimeUs;
  lastTimeUs = currTimeUs;

  // Process R and L wheel encoder values 
  for(int enc=0; enc<2; enc++) {
    diffEncoderCount[enc] = currEncoderCount[enc] - lastEncoderCount[enc];
    lastEncoderCount[enc] = currEncoderCount[enc];
    if((enc==encoderR_e) || (enc==encoderL_e)) {
      currTravelMeters[enc] = (currEncoderCount[enc]/WHEEL_ENCODER_COUNT_PER_ROTATION)*wheelCircumferenceM;
      diffTravelMeters[enc] = (diffEncoderCount[enc]/WHEEL_ENCODER_COUNT_PER_ROTATION)*wheelCircumferenceM;
      velocityMPS[enc] = diffTravelMeters[enc]/(1e-6*diffTimeUs);
    } else {
      currTravelMeters[enc] = (currEncoderCount[enc]/ODOM_ENCODER_COUNT_PER_ROTATION)*ODOM_CIRCUMFERENCE_M;
      diffTravelMeters[enc] = (diffEncoderCount[enc]/ODOM_ENCODER_COUNT_PER_ROTATION)*ODOM_CIRCUMFERENCE_M;
      velocityMPS[enc] = diffTravelMeters[enc]/(1e-6*diffTimeUs);
    }
  }


  // PID loop to regulate R and L wheel speed based on wheel encoder values
  for(int enc=0; enc<2; enc++) {
    // Limit acceleration and decelleration of wheel velocity
    float targetMps = WheelMps[enc];
    float limitedMps = WheelMpsAccLimited[enc];
    float dMpsAcc = wheelAccellerationMaxMpsPs * (diffTimeUs/1e6);

    if(limitedMps != targetMps) {
      if(limitedMps < targetMps) {
        limitedMps = limitedMps + dMpsAcc;
        if(limitedMps > targetMps) limitedMps = targetMps;
      } else if(limitedMps > targetMps) {
        limitedMps = limitedMps - dMpsAcc;
        if(limitedMps < targetMps) limitedMps = targetMps;
      } 
      WheelMpsAccLimited[enc] = limitedMps;
    }

    // error is positive when measured velocity > target velocity
    PidErrorMps[enc] = velocityMPS[enc] - limitedMps;
    PidPropPct[enc] = PidErrorMps[enc] * PidPropCoef[enc];
    PidIntPct[enc] += PidErrorMps[enc] * PidIntCoef[enc];
    if(PidIntPct[enc] > +PidIntPctMax) PidIntPct[enc] = +PidIntPctMax;
    if(PidIntPct[enc] < -PidIntPctMax) PidIntPct[enc] = -PidIntPctMax;

    float pct = 100*(PidPropPct[enc] + PidIntPct[enc]);
    // TODO: limit pct here? or count on limit check in MotorDrivePct()
    MotorPct[enc] = pct;
  }

  // Set wheel motor drive PWM percent
  MotorDrivePct(MotorPct[1], MotorPct[0]);

  return true;
}


void InitEncoders() {
  for(int enc=0; enc<4; enc++) {
    encoder[enc].begin();
    encoder[enc].reset();
  }

  ResetEncoderValues();
}

void InitMotorDrivers(){
  // initialize to stop-braked (100PCT FOR STOP BRAKED)
  PWM_MOTOR_L1 = new RP2040_PWM(PIN_MOTOR_L1, frequency, 100);
  PWM_MOTOR_L2 = new RP2040_PWM(PIN_MOTOR_L2, frequency, 100);
  PWM_MOTOR_R1 = new RP2040_PWM(PIN_MOTOR_R1, frequency, 100);
  PWM_MOTOR_R2 = new RP2040_PWM(PIN_MOTOR_R2, frequency, 100);
}

// +pct = fwd, -pct = rev, 0pct = stop-braked
// pct limited to +-100%
//void MotorDrivePct(int pctL, int pctR) {
void MotorDrivePct(float pctL, float pctR) {
  pctL = -pctL; // opposite rotation as Right Wheel
  // Limit to +-100 pct
  if(pctL>100) pctL=100;
  if(pctL<-100) pctL=-100;
  if(pctL>=0) {
    // Motor Left Forward
    PWM_MOTOR_L1->setPWM(PIN_MOTOR_L1, frequency, 100);
    PWM_MOTOR_L2->setPWM(PIN_MOTOR_L2, frequency, 100-pctL);
  } else {
    // Motor Left Reverse
     PWM_MOTOR_L1->setPWM(PIN_MOTOR_L1, frequency, 100+pctL);
     PWM_MOTOR_L2->setPWM(PIN_MOTOR_L2, frequency, 100);
  }

  pctR = +pctR;
  // Limit to +-100 pct
  if(pctR>100) pctR=100;
  if(pctR<-100) pctR=-100;
  if(pctR>=0) {
    // Motor Right Forward
    PWM_MOTOR_R1->setPWM(PIN_MOTOR_R1, frequency, 100);
    PWM_MOTOR_R2->setPWM(PIN_MOTOR_R2, frequency, 100-pctR);
  } else {
    // Motor Right Reverse
    PWM_MOTOR_R1->setPWM(PIN_MOTOR_R1, frequency, 100+pctR);
    PWM_MOTOR_R2->setPWM(PIN_MOTOR_R2, frequency, 100);
  }

}

uint32_t loopLastMillis;
uint32_t rlLastMillis;

float rlToSec = 0.0;

void setup() {
  // put your setup code here, to run once:
  Serial.begin(155200);
  while (!Serial) {
    ; // wait for serial port to connect. Needed for native USB
  }  

  InitEncoders();

  InitMotorDrivers();
  MotorDrivePct(0, 0);

  InitServos();

  // Init ISR timer 10 msec (100 Hz) for encoder reads
  ITimer1.attachInterruptInterval(10000L, timerInterruptHandler);

  loopLastMillis = millis();
  rlLastMillis = millis();

  Serial.println("Robot 2024 motor/encoder module initialized");
}

int clawPct = 0;
int clawPeriodMs = 0;
bool clawsBusy = false;

void loop() {

 if (Serial.available() > 0) {
    // read the incoming string:
    String incomingString = Serial.readStringUntil('\n');

    // parse string "RL 0.5 0.2" Right wheel = 0.5Mps Left wheel = 0.2 Mps
    float Rv, Lv, Tv;
    int Hz;
    float Fwd, Rev;
    float Acc;
    float wd;
    int n1, n2, n3, n4, n5, n6;

    // Check command for RL wheel velocities in meters/sec
    n1 = sscanf(incomingString.c_str(), "RL %f %f %f", &Rv, &Lv, &Tv);
    // Check command for Odometry Encoder sending rate in Hz
    n2 = sscanf(incomingString.c_str(), "OR %d", &Hz);
    // Check command for wheel offset to correct pull to left or right
    n3 = sscanf(incomingString.c_str(), "WO %f %f", &Fwd, &Rev);
    // Check command for wheel acceleration rate
    n4 = sscanf(incomingString.c_str(), "AR %f", &Acc);
    // Check command for claw positioning
    n5 = sscanf(incomingString.c_str(), "CP %d %d", &clawPct, &clawPeriodMs);
    // Check command for wheel diameter in meters
    n6 = sscanf(incomingString.c_str(), "WD %f", &wd);

    if(n1==3) {
      // Set timeout 
      if (Tv<0.0) Tv=0.0;
      rlToSec = Tv;
      
      // RL wheel velocities
      // compensate for RL offset drift
      if (Rv >= 0) Rv = Rv*wheelFwdOffsetCal;
      else Rv *= wheelRevOffsetCal;
      if (Lv >= 0) Lv = Lv/wheelFwdOffsetCal;
      else Lv *= wheelRevOffsetCal;

      //Limit +- veleocity
      if(Rv > +WheelMpsMax) Rv = +WheelMpsMax;
      if(Rv < -WheelMpsMax) Rv = -WheelMpsMax;
      if(Lv > +WheelMpsMax) Lv = +WheelMpsMax;
      if(Lv < -WheelMpsMax) Lv = -WheelMpsMax;

      WheelMps[encoderR_e] = Rv;
      WheelMps[encoderL_e] = Lv;

      rlLastMillis = millis();

//      Serial.print(Rv);Serial.print(",");Serial.println(Lv);

    } else {
      // Check command for Odometry Encoder sending rate in Hz
      n2 = sscanf(incomingString.c_str(), "OR %d", &Hz);
      // Check command for wheel offset to correct pull to left or right
      n3 = sscanf(incomingString.c_str(), "WO %f %f", &Fwd, &Rev);
      // Check command for wheel acceleration rate
      n4 = sscanf(incomingString.c_str(), "AR %f", &Acc);
        if(n2 == 1) {
        // Update odometry report rate
        // limit rate
        if(Hz>1000) Hz=1000;
        if(Hz<0) Hz=0;

        EncoderSendRateHz = Hz;
        //Serial.print("OR -> "); Serial.println(Hz);

      } else if(n3 == 2) {
        // Update left-right wheel pull offset
        wheelFwdOffsetCal = Fwd;
        wheelRevOffsetCal = Rev;
        //Serial.print("WO -> "); Serial.print(Fwd); Serial.print(", ");Serial.println(Rev);

      } else if(n4 == 1) {
        // update the max wheel acceleration rate
        wheelAccellerationMaxMpsPs = Acc;
        //Serial.print("AR -> "); Serial.println(Acc);

      } else if(n5 == 2) {
        // "CP" operate claws
        clawsBusy = true;
        Serial.print("CP -> "); Serial.print(clawPct);Serial.print(" "); Serial.println(clawPeriodMs);

      } else if(n6 == 1) {
        // "WD" wheel diameter in meters
        wheelCircumferenceM = 2*PI*wd/2.0;
        //Serial.print("WD -> "); Serial.print(wd);Serial.println(" ");

      } else {
        Serial.println("Invalid serial command");
      }
    }
  }

  // If no RL commands in configurable timeout then stop
  if ((rlToSec>0.0) && ((millis() - rlLastMillis) > 1000*rlToSec)) {
    WheelMps[encoderR_e]=0;
    WheelMps[encoderL_e]=0;
  }

  // Open and close claws, does not block
  if (clawsBusy==true) clawsBusy = OperateClaws(clawPct, clawPeriodMs);

  // timer for Odometry send rate, does not block loop execution
  if(EncoderSendRateHz>0) {
    uint32_t loopCurrentMillis = millis();

    // TODO: should be >= 1000.0/rate?
    if( (loopCurrentMillis-loopLastMillis) >= (1000/EncoderSendRateHz) ) {
    
      Serial.print("OD "); 
      Serial.print(currTimeUs); 
      Serial.print(" "); Serial.print(currEncoderCount[encoderR_e]);
      Serial.print(" "); Serial.print(currEncoderCount[encoderL_e]);
      Serial.print(" "); Serial.print(currEncoderCount[encoderX_e]);
      Serial.print(" "); Serial.print(currEncoderCount[encoderY_e]);
      Serial.println("");

      loopLastMillis = loopCurrentMillis;
    }
  } 
}

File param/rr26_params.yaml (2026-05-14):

amcl:
  ros__parameters:
    tf_broadcast: True
    # first_map_only: False
    use_sim_time: False
    alpha1: 0.2
    alpha2: 0.2
    alpha3: 0.2
    alpha4: 0.2
    alpha5: 0.2
    base_frame_id: "base_footprint"
    beam_skip_distance: 0.5
    beam_skip_error_threshold: 0.9
    beam_skip_threshold: 0.3
    do_beamskip: false
    global_frame_id: "map"
    lambda_short: 0.1
    laser_likelihood_max_dist: 2.0
    laser_max_range: 100.0
    laser_min_range: -1.0
    laser_model_type: "likelihood_field"
    max_beams: 60
    max_particles: 2000
    min_particles: 500
    odom_frame_id: "odom"
    pf_err: 0.05
    pf_z: 0.99
    recovery_alpha_fast: 0.1 #0.0
    recovery_alpha_slow: 0.001 #0.0
    resample_interval: 1
    robot_model_type: "nav2_amcl::DifferentialMotionModel"
    save_pose_rate: 0.5
    sigma_hit: 0.2
    # tf_broadcast: true
    transform_tolerance: 1.0
    update_min_a: 0.01 #0.2
    update_min_d: 0.01 #0.25
    z_hit: 0.5
    z_max: 0.05
    z_rand: 0.5
    z_short: 0.05
    scan_topic: scan_fix

amcl_map_client:
  ros__parameters:
    use_sim_time: False

amcl_rclcpp_node:
  ros__parameters:
    use_sim_time: False

bt_navigator:
  ros__parameters:
    use_sim_time: False
    global_frame: map
    robot_base_frame: base_link
    odom_topic: /odom
    default_bt_xml_filename: "navigate_w_replanning_and_recovery.xml"
    bt_loop_duration: 10
    default_server_timeout: 20
    enable_groot_monitoring: True
    groot_zmq_publisher_port: 1666
    groot_zmq_server_port: 1667
    plugin_lib_names:
    - nav2_compute_path_to_pose_action_bt_node
    - nav2_compute_path_through_poses_action_bt_node
    - nav2_follow_path_action_bt_node
    - nav2_back_up_action_bt_node
    - nav2_spin_action_bt_node
    - nav2_wait_action_bt_node
    - nav2_clear_costmap_service_bt_node
    - nav2_is_stuck_condition_bt_node
    - nav2_goal_reached_condition_bt_node
    - nav2_goal_updated_condition_bt_node
    - nav2_initial_pose_received_condition_bt_node
    - nav2_reinitialize_global_localization_service_bt_node
    - nav2_rate_controller_bt_node
    - nav2_distance_controller_bt_node
    - nav2_speed_controller_bt_node
    - nav2_truncate_path_action_bt_node
    - nav2_goal_updater_node_bt_node
    - nav2_recovery_node_bt_node
    - nav2_pipeline_sequence_bt_node
    - nav2_round_robin_node_bt_node
    - nav2_transform_available_condition_bt_node
    - nav2_time_expired_condition_bt_node
    - nav2_distance_traveled_condition_bt_node
    - nav2_single_trigger_bt_node
    - nav2_is_battery_low_condition_bt_node
    - nav2_navigate_through_poses_action_bt_node
    - nav2_navigate_to_pose_action_bt_node
    - nav2_remove_passed_goals_action_bt_node
    - nav2_planner_selector_bt_node
    - nav2_controller_selector_bt_node
    - nav2_goal_checker_selector_bt_node

bt_navigator_rclcpp_node:
  ros__parameters:
    use_sim_time: False

########################## this seems to work OK but bad tuning #################################
# controller_server:
#   ros__parameters:
#     #To use the use_realtime_priority feature, you use set the following inside of /etc/security/limits.conf 
#     # to give userspace access to elevated prioritization permissions: 
#     #<username> soft rtprio 99 <username> hard rtprio 99
#     use_realtime_priority: True

#     use_sim_time: False
#     controller_frequency: 10.0
#     min_x_velocity_threshold: 0.001
#     min_y_velocity_threshold: 0.5
#     min_theta_velocity_threshold: 0.001 
#     failure_tolerance: 0.3
#     progress_checker_plugin: "progress_checker"
#     goal_checker_plugins: ["general_goal_checker"]
#     controller_plugins: ["FollowPath"]

#     # Progress checker parameters
#     progress_checker:
#       plugin: "nav2_controller::SimpleProgressChecker"
#       required_movement_radius: 0.1 #0.0 #0.5
#       movement_time_allowance: 10.0

#     general_goal_checker:
#       stateful: True
#       plugin: "nav2_controller::SimpleGoalChecker"
#       xy_goal_tolerance: 0.25 #0.05 #0.25
#       yaw_goal_tolerance: 0.1 #0.05 #0.25
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

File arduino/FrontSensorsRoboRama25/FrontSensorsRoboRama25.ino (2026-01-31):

/*
  Read an 8x8 array of distances from the VL53L5CX
  By: Nathan Seidle
  SparkFun Electronics
  Date: October 26, 2021
  License: MIT. See license file for more information but you can
  basically do whatever you want with this code.

  This example shows how to read all 64 distance readings at once.

  Feel like supporting our work? Buy a board from SparkFun!
  https://www.sparkfun.com/products/18642

  mrw 1/30/2024 controls 3 sensors and prints array on 8 lines
  mrw 3/15/2024 Could not control the BNO055 sensor, the libs seem to clash
  mrw 3/15/2024 Try to control the INA228 current sensor for battery

  mrw 3/8/2025 Copied file for RoboRama2025
  mrw 3/8/2025 Connect Wire1(2,3) to I2C connector and INA228 code
  mrw 3/9/2025 Add VL53L4Cx and BNO055 code
  mrw 4/12/2025 Added rear range sensors OPT3101

  mrw 1/31/2026 Copied 2025 file for RoboRama2026
    remove TOF Vl53L4Cx and rear OPT sensors
    disable IMU sensor (maybe enable later but leave the code)

*/

#include <Wire.h>

#include <Adafruit_INA228.h>
Adafruit_INA228 ina228 = Adafruit_INA228();

// #include <Adafruit_Sensor.h>
// #include <Adafruit_BNO055.h>
// #include <utility/imumaths.h>
// Adafruit_BNO055 bno = Adafruit_BNO055(55, 0x28, &Wire1);

// // This lib also works with VL53L4CX 
// #include "SparkFun_VL53L1X.h" //Click here to get the library: http://librarymanager/All#SparkFun_VL53L1X
// SFEVL53L1X frontRangeSensor(Wire1);

#include <SparkFun_VL53L5CX_Library.h> //http://librarymanager/All#SparkFun_VL53L5CX
// Create 3 sensors Left, Front, Right
SparkFun_VL53L5CX myImagerLL;
SparkFun_VL53L5CX myImagerLR;
SparkFun_VL53L5CX myImagerRL;
SparkFun_VL53L5CX myImagerRR;
VL53L5CX_ResultsData measurementData; // Result data class structure, 1356 byes of RAM

// // Rear range sensors FOV 50+60+50
// #include "OPT3101.h"
// OPT3101 opt3101Sensors;
// uint16_t opt3101SensorsAmplitudes[3];
// int16_t opt3101SensorsDistances[3];


int imageResolution = 0; //Used to pretty print output
int imageWidth = 0; //Used to pretty print output
int sharpenerPct = 30; // default 5%
int integrationTimeMsec = 20; // default 5ms


#define pinSDA 0
#define pinSCL 1
#define pinSDA_1 2
#define pinSCL_1 3

#define pinTofLPLL 4 /* sensor enable active low */
#define pinTofLPLR 5
#define pinTofLPRL 6
#define pinTofLPRR 7
#define pinTofLED 8
#define pinTofPwrEn 14 /* 3.3V power down LOW */


//#define i2cImuAddr  0x28 /* BNO055? */
#define i2cTofAddrD 0x29 /* default TOF */
#define i2cTofAddrLL 0x2A /* Left L TOF*/
#define i2cTofAddrLR 0x2B /* Left R TOF */
#define i2cTofAddrRL 0x2C /* Right L TOF */
#define i2cTofAddrRR 0x2D /* Right R TOF */
//#define i2cCurrAddr 0x40 /* INA228?*/

//#define rangingFreqHz 10
//#define resolution (8*8) /*8*8 or 4*4 */

//////////////////////////////////////////////////////////
// enable 3.3V regulator control pin and cycle the power
void init3v3Regulator(void){
  // power cycle to reset default i2c address on VL53L5 devices
  // also it seems like simply enabling the PwrEn pin causes a glitch
  pinMode(pinTofPwrEn, OUTPUT);
  digitalWrite(pinTofPwrEn, LOW);
  delay(100);
  digitalWrite(pinTofPwrEn, HIGH);
  delay(100);
}

///////////////////////////////////////////////////////////
// INA228 current sensor
#define INA228_SAMPLERATE_HZ 1
int batDataPeriodMs = 0;
uint32_t lastInaMillis = 0;
void cfgBatDataRate(int hz){
  if(hz>0 && hz<=10) batDataPeriodMs = 1000/hz;
  else batDataPeriodMs = 0;
}
void initINA228(void) {

  cfgBatDataRate(INA228_SAMPLERATE_HZ);

  if (!ina228.begin(64,&Wire1)) {
    Serial.println("Couldn't find INA228 chip");
    while (1)
      ;
  }
//  Serial.println("Found INA228 chip");
  // the shunt R=0.015 Ohm and max current A=3
  ina228.setShunt(0.015, 3.0);
  ina228.setAveragingCount(INA228_COUNT_16);
  // reading 1/sec
  ina228.setVoltageConversionTime(INA228_TIME_540_us);
  ina228.setCurrentConversionTime(INA228_TIME_540_us);

  Serial.println("INA228 sensor initialized OK");
  
  lastInaMillis = millis();
}

void getInaSensorData(){
  if (batDataPeriodMs==0) return;
  if ((millis() - lastInaMillis) >= batDataPeriodMs) {
    lastInaMillis = millis();
    // convert to integers since in mv and ma
    int vbus_mv = ina228.readBusVoltage();
    int curr_ma = ina228.readCurrent();
    int temp_c = ina228.readDieTemp();

    // send message
    Serial.print("BT ");
    Serial.print(vbus_mv);Serial.print(" ");
    Serial.print(curr_ma);Serial.print(" ");
    Serial.print(temp_c);Serial.println("");
  }
}

// ///////////////////////////////////////////////////////////////
// // BNO055 IMU sensor
// /* Set the delay between fresh samples */
// #define BNO055_SAMPLERATE_HZ (50)
// #define BNO055_CALRATE_HZ (1)
// int imuDataRateMs = 0;
// int imuCalRateMs = 0;
// uint32_t imu_last_millis = 0;
// uint32_t cal_last_millis = 0;

// void cfgImuDataRate(int hz) {
//   if (hz>0 && hz<=50) imuDataRateMs = 1000/hz;
//   else imuDataRateMs = 0;
//   imu_last_millis = millis();
// }
// void cfgImuCalRate(int hz) {
//   if (hz>0 && hz<=10) imuCalRateMs = 1000/hz;
//   else imuCalRateMs = 0;
//   cal_last_millis = millis();
// }

// void initImuSensor(){
//   /* Initialise the sensor */
//   if(!bno.begin( OPERATION_MODE_NDOF)) {
//     /* There was a problem detecting the BNO055 ... check your connections, freezing!! */
//     Serial.println("Ooops, no BNO055 detected ... Check your wiring or I2C ADDR, freezing!");
//     while(1);
//   }

//   // Write calibration data to jump start IMU operation
//   uint8_t imuCalData[22] = {222,255,251,255,238,255,110,0,117,1,51,1,255,255,254,255,255,255,232,3,17,3};
//   bno.setSensorOffsets(imuCalData);

//   bno.setExtCrystalUse(true);

//   cfgImuDataRate(BNO055_SAMPLERATE_HZ);
//   cfgImuCalRate(BNO055_CALRATE_HZ);

//   imu_last_millis = millis();
//   cal_last_millis = millis();
// }

// void getImuSensorData(void){
//   if (imuDataRateMs==0) return;
//   if((millis()-imu_last_millis)>=imuDataRateMs) {
//     imu_last_millis = millis();

//     /* Get a new sensor event */
//     sensors_event_t angVelocityData, linearAccelData;
//     bool a = bno.getEvent(&angVelocityData, Adafruit_BNO055::VECTOR_GYROSCOPE);
//     bool v = bno.getEvent(&linearAccelData, Adafruit_BNO055::VECTOR_LINEARACCEL);
//     imu::Quaternion quat = bno.getQuat();
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

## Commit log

2026-01-19 init a copy of roborama25_ws for amodification as the roborama26 6 can robot
    [PWR board.kicad_pcb, PWR board.kicad_sch, Roborama2025-CamMount.amf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]
2026-01-20 Started 3D changes
    [PWR board.kicad_pcb, PWR board.kicad_sch, Roborama2025.FCStd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]
2026-01-20 3D laser on bottom + start of can holder
    [Roborama2026.FCStd]
2026-01-28 new 3D printed sensor mounts
    [Roborama2026-CamMount.3mf, Roborama2026-CanBasket.3mf, Roborama2026-Lasermount.3mf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]
2026-01-31 OPENMV cam python files changed to detect cans better (I hope) Front Sensor Arduino code - Commented out front L4 TOF, rear OPT sensors code and commented out IMU code
2026-02-02 changed filename prefixe roborama25_ to rr26_
    [rr26.urdf]
2026-02-02 removed front L4 tof and rear OPT sensors from sensor node and urdf
    [rr26.urdf]
2026-02-03 Scaled battery voltage correctly Use opnemv blob height to determine distance. Use blob horozntal location and distance to detrmine the map XY coordinates of the detected can.
    [rr26.urdf]
2026-02-04 rr26_params: removed L4 TOF range sensor and rear IR range sensors form obstcal detection
2026-03-11 urdf: removed front range sensor L4 Added BarrelCans custom msg Added Barrel Race button detection Started can xy Lidar function colcon build OK
    [rr26.urdf]
2026-03-17 Added custom messages for Barrel detetction can xy node barrel/can detection code creates a Barrels.msg topic TODO: Fix detect code for barrel in front at 0 deg or so
    [rr26_can_xy_node_lc.py]
2026-03-21 can xy node: Added degub print controller node: Added barrel race code wheel controller: added dubug print
2026-03-21 Changed main() in lifecycle nodes to not rclpy.shutdown() and let lifecycle context manager do its thing. Seemed to fif Lidar shutdown issue
    [rr26_can_xy_node_lc.py, rr26_controller_node_lc.py, rr26_front_sensors_node_lc.py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]
2026-03-23 Changed all lifecycle nodes main() to allow lifecycle context shutdown Put all node timers in a callback group Cleared all serial port read buffers in timers looped on serial readline until empty Run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
    [rr26_can_xy_node_lc.py, rr26_controller_node_lc.py, rr26_front_sensors_node_lc.py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]
2026-03-23 Failed to get lifecycle nodes to be reliable. Saving before converting to normal nodes
    [rr26_front_sensors_node_lc.py, rr26_openmv_serial_node_lc.py, rr26_wheel_controller_node_lc.py]
2026-03-24 Enabled camera can detection
2026-03-25 Updated wheel controller and front sensors nodes to non-lifecycle
2026-03-26 Enabled front sensors serial processing -> OK
2026-03-26 enabled wheel controler node serial processing
2026-04-01 barrel race state B1B: use camera blob to head toward can and stop at a short distance away.
    [rr26_controller_node.py]
2026-04-02 controller: senses barrel using Lidar and goes around the barrel
2026-04-03 controller: barrel race goes around barrel 1, then tries to go around barrel 2 but it mistakes an object for the barrel and fails
    [rr26_controller_node.py]
2026-04-06 went around all 3 barrels but gets distracted, maybe Lidar doesnt always detect cans. The caster might need adjustment to keep level.
2026-04-08 Moved barrel detect code to new rr26_lidar_can_node. Loosened the barrel detection criteria
    [rr26_can_xy_node.py, rr26_lidar_can_node.py]
2026-04-10 tightened up barrel detect angles when going around barrels
    [rr26_controller_node.py]
2026-04-12 Barrel race: Fixed gotoHome angle correction Made linX = linX0 placement more consistant in states Tightend up lidar can detect in aroundBnA states
    [rr26_controller_node.py]
2026-04-13 barrel race: gotoHome added currentY to help got to center of home (0,0)
2026-04-13 barrel race: changed speed from 0.1 to 0.25 -> works OK but overshoots anges as expected
    [rr26_controller_node.py]
2026-04-15 wheels: increase accel limt to 100 m/s/s basically no limit barrel: linX0=0.25 OK but some overshoot exiting barrels and lots of overshoot using camera to go toward barrel
    [rr26_controller_node.py, rr26_wheel_controller_node.py]
2026-04-15 using .bash_rr26 reset the USB hub untill both the camera and lidar devices are ready
2026-04-17 barrel race: I think I improved the accuracy of the angle when exiting a barrel by adjusting the odom angle with the angular velocity and an estimate of the odom lag
2026-04-17 Corrected robot pose using current linear velocity and odom lag estimate
    [rr26_controller_node.py]
2026-04-17 barrel race: attempt to correct camera can detect angle using angular velocity and estimated lag time
    [rr26_controller_node.py]
2026-04-17 barrel race: attempt to correct lidar barrel detect angle
    [rr26_controller_node.py]
2026-04-17 barrel race: adjusted camera and lidar angle lag correction and now it seems to be OK at linX=0.3
    [rr26_controller_node.py]
2026-04-18 lidar: physically change the lidar direction -180 deg which "fixes" the discontinuity (begin-end- scannin g) of the scan data in front of the robot and moves the distortion to behind the robot. Adjus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
    [rr26.urdf]
2026-04-18 added new scan_fix_node which publishes a new /scan_fix message The node does not fix anything yet but the plumbing is in place
    [rr26_lidar_can_node.py, rr26_scan_fix_node.py]
2026-04-19 Attempt to fix angular lidar scan motion error. Need to develop a metric to measure fix is good
    [rr26_scan_fix_node.py]
2026-04-21 wheels node: filtered out non "OD" serial messages before puting into encoder topic teleop node: increased max rotation velocity scan fix node: attempt to motion compensate Lidar - commented out for 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
    [rr26_scan_fix_node.py, rr26_teleop_node.py, rr26_wheel_controller_node.py]
2026-04-21 rr26 controller node: changed barrel 3 breakout angle that was being overshot and missed at 0.3m/s
    [rr26_controller_node.py]
2026-04-21 wheels node: trimmed wheelDistance to get more accurate odom pose angle tracking
2026-04-22 scan fix node: changed to timestamp the fixed scan topic to the end of the scan. Calculated linCurve once. calculated odom acceleration for future data extrapolation/interpolation
    [rr26_scan_fix_node.py, rr26_wheel_controller_node.py]
2026-04-23 scan fix node: angular vel fix OK but still needs better lag fix
    [rr26_scan_fix_node.py]
2026-04-23 scan fix node: asked Claude AI to help fix it. Claude also made promatting changes.
    [rr26_scan_fix_node.py]
2026-04-24 scan fix node: hopefully final tweak for lag compensation
    [rr26_scan_fix_node.py]
2026-04-24 barrel race: tightened the state timeouts, tweaked exit angles etc.
    [rr26_controller_node.py, rr26_scan_fix_node.py]
2026-04-24 barrel race: reduced arc to point to barrel 1 which should improve camera blob detection of barrel
2026-04-29 barrel race: gotoBnB added Lidar can detect to break out -> sems to work better than camera blob alone
2026-04-29 barrel race: 0.5 m/s is OK, but will fail some times
    [rr26_controller_node.py]
2026-05-03 cleaned up barrel race in controller_node and barrel_race files controller: quick trip- changed home length to 8 ft. Enabled wheels acceleration during quicktrip. stopped for 0.1 sec after going forw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
2026-05-05 scan_fix_node: cleaned up linear motion fix. It seems to fix OK
    [rr26_scan_fix_node.py]
2026-05-06 controller: 6can - restored range detection scan_fix: Published /front_range using Lidar scan data
2026-05-09 params: amcl - changed scan topic to /scan_fix Added /scan_nocan info to obstical but not enabled controller: 6can- changed home arena to 8ft Changed TOFL4 range sensor to /front_range using Lidar sc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
    [rr26_controller_node.py, rr26_params.yaml, rr26_scan_fix_node.py]
2026-05-14 Claws work now
2026-05-14 params: Disables global cost map obsticals controller node: gotoCanTF- stopped 2x robot radius to allow room to use TOF sensors to center and approach can Modified dist calcs for new range sensor bas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
2026-05-22 controller_node: gotoCanTF - break loop when close to can getPoseFromTF - use current time when fetchinf transform (this helped lot in 6can) run_approachCan - added can detect test using expected num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
